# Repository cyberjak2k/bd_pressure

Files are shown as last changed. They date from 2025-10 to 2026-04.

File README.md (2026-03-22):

#  Auto PA Calibration

## Overview 

Pressure Advance (PA) is one of the most impactful tuning parameters in FDM printing, yet calibrating it correctly is time-consuming, requires print-specific expertise, and must be repeated whenever filament, speed, or temperature changes.

**bd_pressure** solves this with a dedicated strain-gauge sensor module that measures extruder pressure directly — without printing a single line. It runs an automated calibration routine by simulating extrusion pressure behaviour during acceleration and deceleration, then reports the optimal PA value to the printer firmware over USB or I2C.

The same hardware doubles as a high-precision nozzle probe for bed levelling, acting as a drop-in switch-type endstop on the Z− pin.

 
 
---
Video : https://youtu.be/xD0XgPfmwlg



## Features

| Feature | Description |
|---|---|
| **Automatic PA calibration** | No calibration prints. Extruder-only routine measures pressure response directly. |
| **Nozzle probe** | Strain-gauge contact detection for Z homing, Z tilt, bed mesh or work with eddy bed scan sensor. |
| **EMI immunity** | Sensor mounted zero-distance to PCB — minimal analog trace length eliminates noise pickup. |
| **USB & I2C** | Flexible host connectivity; works with Klipper and compatible setups. |
| **Broad compatibility** | Mounting footprint compatible with E3D and Voron toolhead ecosystems. |

---

## How It Works

### Mode 1 — Pressure Advance Calibration

Rather than printing calibration patterns and analysing them visually, bd_pressure directly measures the mechanical relationship between extruder motor acceleration and filament pressure at the nozzle.

1. The extruder motor runs a controlled acceleration/deceleration sequence.
2. The strain gauge measures the resulting force in real time.
3. The on-board MCU fits a pressure-vs-acceleration curve and derives the optimal PA value.
4. The result is sent to the printer firmware via USB or I2C.

This approach is conceptually similar to the automated calibration used in the Bambu Lab A1, but uses a **strain gauge** rather than an eddy current sensor — providing a direct force measurement.

### Mode 2 — Nozzle Probe

bd_pressure operates as a standard switch-type endstop sensor:

1. The printer issues a normal Z homing move.
2. As the nozzle contacts the bed, the strain gauge detects the resulting force change.
3. The module asserts a signal on the endstop output — compatible with any mainboard Z− pin.
4. No additional firmware plugin is required for basic probe operation.

---

 

---

---
 
## Installation & Documentation
 
Full installation guide, wiring diagrams, and Klipper configuration reference:
 
**[pandapi3d.cn/en/bdpressure/home](https://pandapi3d.cn/en/bdpressure/home)**


---
 
## Community & Support
 
| Channel | Link |
|---|---|
| Discord | [discord.gg/z6ahddnGVU](https://discord.gg/z6ahddnGVU) |
| Facebook group | [facebook.com/groups/380795976169477](https://www.facebook.com/groups/380795976169477) |
| Shop | [pandapi3d.com](https://www.pandapi3d.com/product-page/bdpressuree) |

---

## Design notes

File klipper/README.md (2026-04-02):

## klipper 

#### 1. Install software module
```
cd  ~
git clone https://github.com/markniu/bd_pressure.git
chmod 777 ~/bd_pressure/klipper/install.sh
~/bd_pressure/klipper/install.sh
```

#### 2. Configure Klipper

Add [include bd_pressure.cfg] into the printer.cfg , and modify the pins to your actual use in the section [probe] and [bdpressure bd_pa]

#### 3. OrcaSlicer:

1. Disable the Pressure advance in the Material settings.

2. Add the following G-code lines into the beginning of the Start_Gcode in the slicer, then it will do pressure advance calibration with your setting and automatically set the right PA value. 
```
G28                    ; Home all the axis
G1 Z30                 ; move to the poop position
G1 X240 Y240   
PA_CALIBRATE NOZZLE_TEMP=[first_layer_temperature] MAX_VOLUMETRIC=[filament_max_volumetric_speed] ACC_WALL=[outer_wall_acceleration]  TRAVEL_SPEED=[travel_speed]  ACC_TO_DECEL_FACTOR=[accel_to_decel_factor]
```
#### 3. Prusa Slicer:
```
G28                    ; Home all the axis
G1 Z30                 ; move to the poop position
G1 X240 Y240   
PA_CALIBRATE NOZZLE_TEMP=[first_layer_temperature] MAX_VOLUMETRIC=[filament_max_volumetric_speed] ACC_WALL=[outer_wall_acceleration]  TRAVEL_SPEED=[travel_speed]  MINIMUM_CRUISE_RATIO=0.5 #ACC_TO_DECEL_FACTOR=[accel_to_decel_factor] this klipper specifc variable was replaced in Klipper with MINIMUM_CRUISE_SPEED. and the 0.5 is the default 50% which can be adjusted to suite the printer's capabilities. 
```

#### bd_pressure.cfg considerations:
If you have both a bd_pressure and as well bd_width, each has the same by-id UUID because of this, each plugin will try and take control of the first device it can see with the UUID for the USB example 
So you would:
unplug bd_pressure usb cable, then use ls /dev/serial/by-path and take note of the entries there, then plug it back in and use the new entry that appears in place of the "ReplaceWithYourDevicePath" in the example below. 
you will only have to repeat this process if you change what port the bd_pressure is plugged into.
as well you will need to do this in bd_width.cfg as well as both devices will still show the by-id string and can still select the wrong device. 

##   usb example 
# port:usb
# serial:/dev/serial/by-id/usb-1a86_USB_Serial-if00-port0  ## uncomment this if you only have bd_pressure an no bd_width device
# serial:/dev/serial/by-path/ReplaceWithYourDevicePath  # Uncomment this if you have both bd_pressure and bd_width. You need to use ls /dev/serial/by-path , and determine which entry belongs to bd_pressure. 
#if you change the port it's plugged into, you will need to adjust this after doing so to reflect the new usb port you moved it to. 
#you also repeat this with bd_width.cfg to resolve the conflict.
# baud:38400

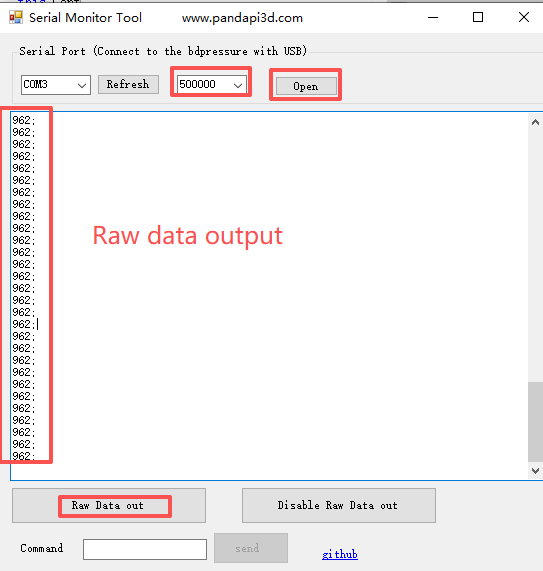
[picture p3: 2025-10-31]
tool/data.png

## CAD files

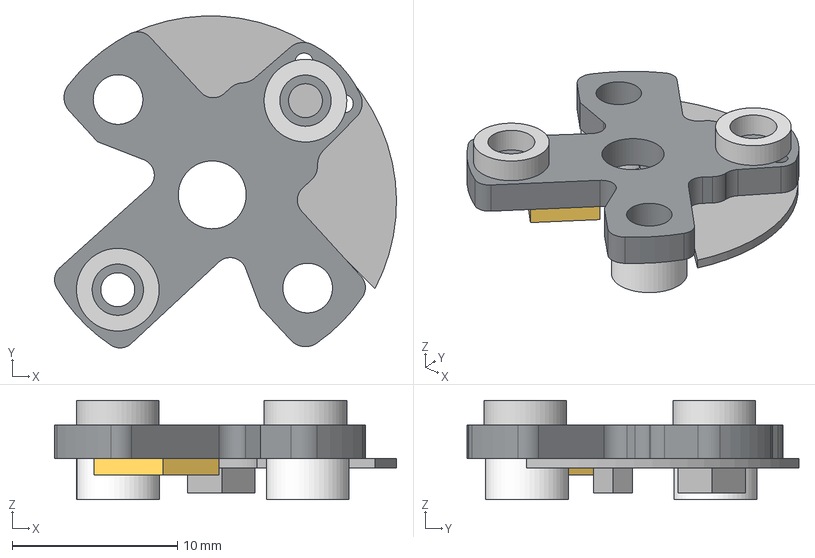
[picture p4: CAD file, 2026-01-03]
hardware/bdpressureE/bda.step
20.7 x 20.1 x 6.00 mm

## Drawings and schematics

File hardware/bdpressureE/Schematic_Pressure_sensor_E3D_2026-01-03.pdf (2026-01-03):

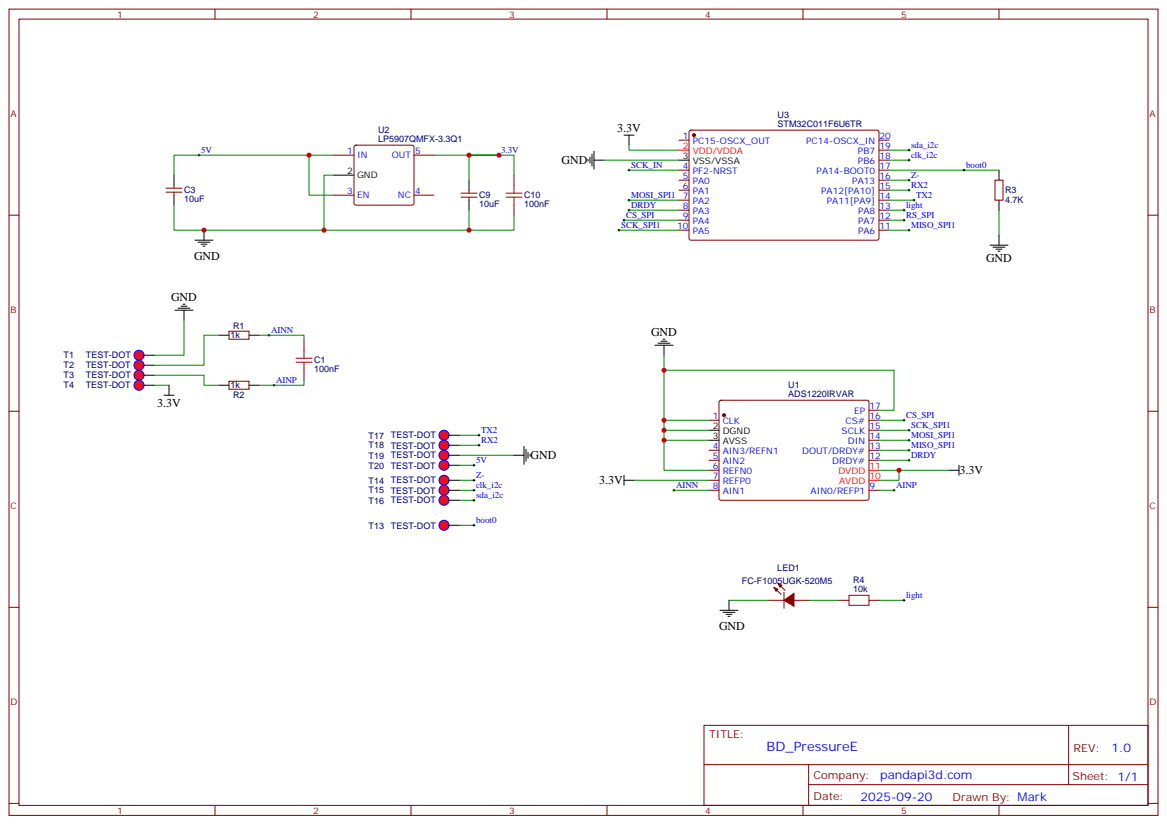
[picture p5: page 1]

ADS1220IRVAR
AVDD 10 DVDD 11 DRDY# 12 DOUT/DRDY# 13 DIN 14 SCLK 15 CS# 16 EP 17

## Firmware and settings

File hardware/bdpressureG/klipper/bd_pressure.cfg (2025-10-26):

[probe]
pin: MKS_THR:PB9
x_offset: 0
y_offset: 0
z_offset: -0.14
speed: 10
samples: 2
samples_result: median
sample_retract_dist: 3
samples_tolerance: 0.02
samples_tolerance_retries: 5

[bdpressure bd_pa]
##   usb example 
#port:usb
#serial:/dev/serial/by-path/platform-xhci-hcd.0.auto-usb-0:1.2:1.0-port0

##   i2c example
port:i2c
i2c_mcu: MKS_THR
i2c_software_scl_pin:MKS_THR:PB3
i2c_software_sda_pin:MKS_THR:PB4



[gcode_macro PA_STATE]
gcode:
    {% set status = printer["bdpressure bd_pa"].state %} 
    { action_respond_info("status:%s %d"%(status,params.T|int)) }


[gcode_macro PA_E]
gcode:   
      {% set status = printer["bdpressure bd_pa"].state %} 
      {% set i = params.I|int %} 
      #{ action_respond_info("status:%f %d"%(params.STEP|float,i)) }
      {% if status=='START' %}
        {% set pressure_ad = 0 + i*(params.STEP|float) %}
        SET_PRESSURE_ADVANCE ADVANCE={pressure_ad}
        {% set y_step =38.75 + i*3.5 %}
        G1 X78 Y{y_step} F{params.T_SPEED|int}
        G1 F{params.L_SPEED|int}
        G1 X98 Y{y_step} E.92643
        G1 F{params.H_SPEED|int}
        G1 X138 Y{y_step} E1.85285
        G1 F{params.L_SPEED|int}
        G1 X158 Y{y_step} E.92643
        SET_BDPRESSURE NAME=bd_pa COMMAND=READ VALUE={pressure_ad}
      {% endif %}
    

[gcode_macro PA_CALIBRATE]
gcode:
    # PA_CALIBRATE NOZZLE_TEMP=[first_layer_temperature] MAX_VOLUMETRIC=[filament_max_volumetric_speed] ACC_WALL=[outer_wall_acceleration]
    # TRAVEL_SPEED=[travel_speed]  ACC_TO_DECEL_FACTOR=[accel_to_decel_factor]

    ### temperature=210,ACCEL_TO_DECEL=10000,ACCEL=8000,SQUARE_CORNER_VELOCITY=5
    {% set NOZZLE_TEMP = 210 %}
    {% if params.NOZZLE_TEMP %}
	      { action_respond_info("nozzle TEMPERATURE %s "%params.NOZZLE_TEMP) }
	      {% set NOZZLE_TEMP = params.NOZZLE_TEMP|default(210)|float %}
	  {% endif %}
    {% set ACC_WALL = 4000 %}
    {% if params.ACC_WALL %}
	      { action_respond_info("ACC_out_WALL %s "%params.ACC_WALL) }
	      {% set ACC_WALL = params.ACCEL_TO_DECEL|default(4000)|float %}
	  {% endif %}

    {% set SQUARE_CORNER_SPEED = 9 %}
    {% if params.SQUARE_CORNER_VELOCITY %}
	      { action_respond_info("SQUARE_CORNER_VELOCITY %s "%params.SQUARE_CORNER_VELOCITY) }
	      {% set SQUARE_CORNER_SPEED = params.SQUARE_CORNER_VELOCITY|default(9)|float %}
	  {% endif %}
    ### travel_speed=400, max_volumetric_speed = [filament_max_volumetric_speed]
    ##  low_speed = (1020/20)*max_volumetric_speed
    ##  high_speed = (10740/20)*max_volumetric_speed
    {% set ACC_TO_DECEL_FAC = 0.5 %}
    {% set MIN_CRUISE = 0.5 %}
    {% if params.ACC_TO_DECEL_FACTOR %}
	      { action_respond_info("accel_to_decel_factor %s "%params.ACC_TO_DECEL_FACTOR) }
	      {% set ACC_TO_DECEL_FAC =  params.ACC_TO_DECEL_FACTOR.replace("%", "").strip() | float / 100    %}
	      {% set MIN_CRUISE = 1-ACC_TO_DECEL_FAC|float %}
          { action_respond_info("ACC_TO_DECEL_FACTOR %s "%ACC_TO_DECEL_FAC) }
          { action_respond_info("MIN_CRUISE %s "%MIN_CRUISE) }
	  {% endif %}
    {% set ACC_TO_DEC = ACC_TO_DECEL_FAC*ACC_WALL %}
    
    {% set TRAVEL_SPEED = 400 %}
    {% if params.TRAVEL_SPEED %}
	      {% set TRAVEL_SPEED = params.TRAVEL_SPEED|default(400)|float * 60 %}
          { action_respond_info("travel_speed %s/60 "%TRAVEL_SPEED) }
	  {% endif %}
    {% set MAX_VOLUMETRIC = 20 %}
    {% if params.MAX_VOLUMETRIC %}
	      { action_respond_info("filament_max_volumetric_speed %s "%params.MAX_VOLUMETRIC) }
	      {% set MAX_VOLUMETRIC = params.MAX_VOLUMETRIC|default(20)|float %}
	  {% endif %}
    {% set low_speed = 51*MAX_VOLUMETRIC %}
    { action_respond_info("low_speed %f "%low_speed) }
    {% set high_speed = 537*MAX_VOLUMETRIC %}
    { action_respond_info("high_speed %f "%high_speed) }
    
    #  volum=[filament_max_volumetric_speed]
    #  travel=[travel_speed] [accel_to_decel_factor] acc=[outer_wall_acceleration] temper=[first_layer_temperature]
    #SET_KINEMATIC_POSITION Z={z_current}
    {% set z_current=printer.toolhead.position.z %}
    G90
    G21
    M83 
    M109 S{NOZZLE_TEMP}
    G1 E4
    SET_PRESSURE_ADVANCE ADVANCE=0.04; Override pressure advance value
    SET_VELOCITY_LIMIT ACCEL={ACC_WALL} ACCEL_TO_DECEL={ACC_TO_DEC}
    SET_VELOCITY_LIMIT ACCEL={ACC_WALL} MINIMUM_CRUISE_RATIO={MIN_CRUISE}
    SET_VELOCITY_LIMIT SQUARE_CORNER_VELOCITY={SQUARE_CORNER_SPEED}
    
    
    SET_STEPPER_ENABLE STEPPER=stepper_x ENABLE=1
    SET_STEPPER_ENABLE STEPPER=stepper_y ENABLE=1
    SET_BDPRESSURE NAME=bd_pa COMMAND=START
    M400
    G4 P1000
    {% set y_step = 38.75 %}
    {% set pressure_ad = 0 %}
    {% set pressure_step = 0.002 %}
    
    G1 F{high_speed}
    G1 X78 Y{y_step} E9.92204
    M400
    G4 P4000
    G1 F{low_speed}
    G1 X98 Y{y_step} E.92643
    G1 X138 Y{y_step} E1.85285
    G1 X158 Y{y_step} E.92643
    G1 X78 Y{y_step} F{TRAVEL_SPEED}
    ######
    M400
    {% for i in range(50) %}
       PA_E STEP={pressure_step} T_SPEED={TRAVEL_SPEED} H_SPEED={high_speed} L_SPEED={low_speed} I={i}
    {% endfor %}
    M400 
    SET_BDPRESSURE NAME=bd_pa COMMAND=STOP
    G4 P1000
    SET_KINEMATIC_POSITION X=0 Y=0
    G28 X
    G28 Y
    SET_KINEMATIC_POSITION Z={z_current}
    #G28 Z

    
    

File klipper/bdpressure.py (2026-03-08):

import logging
import math
import statistics
import serial
import os


from . import bus
from . import filament_switch_sensor


BDP_CHIP_ADDR = 4
BDP_I2C_SPEED = 100000
BDP_REGS = {
     '_version' : 0x0,
     '_measure_data' : 15,
      'pa_probe_mode' : 48, ## 7= CLOCK_OSR_16384  2=CLOCK_OSR_512
     'raw_data_out' : 49,
     'probe_thr' : 50,
     'rang' : 51,
     'reset_probe' : 52,
     'invert_data' : 53

}

PIN_MIN_TIME = 0.100
RESEND_HOST_TIME = 0.300 + PIN_MIN_TIME
MAX_SCHEDULE_TIME = 5.0


class BD_Pressure_Advance:
    def __init__(self, config):
        self.printer = config.get_printer()
        self.reactor = self.printer.get_reactor()
        self.port = config.get("port")
        self.old_res=''
        # if config.get("resistance1", None) is None:
        self.thrhold = config.getint('thrhold', 4, minval=1) 
        if "i2c" in self.port:  
            self.i2c = bus.MCU_I2C_from_config(config, BDP_CHIP_ADDR, BDP_I2C_SPEED)
        elif "usb" in self.port:
            self.usb_port = config.get("serial")
            self._baud = config.getint('baud', 38400, minval=2400) 
            #THRHOLD
           # baudrate = self.usb_port = config.get("") #38400
            self.usb = serial.Serial(self.usb_port, self._baud,timeout=0.5)
            self.usb.reset_input_buffer()
            self.usb.reset_output_buffer()
        self.PA_data = []    
        self.bd_name = config.get_name().split()[1]     
        self.gcode = self.printer.lookup_object('gcode')
        self._invert_stepper_x, self.mcu_enable_pin_x = self.enable_pin_init(config,"stepper_x")
        self._invert_stepper_x1, self.mcu_enable_pin_x1 = self.enable_pin_init(config,"stepper_x1")
        self._invert_stepper_y, self.mcu_enable_pin_y = self.enable_pin_init(config,"stepper_y")
        self._invert_stepper_y1, self.mcu_enable_pin_y1 = self.enable_pin_init(config,"stepper_y1")
        self.last_state = 0
        self.gcode.register_mux_command("SET_BDPRESSURE", "NAME", self.bd_name,
                                   self.cmd_SET_BDPRESSURE,
                                   desc=self.cmd_SET_BDPRESSURE_help)   
        self.printer.register_event_handler('klippy:ready',
                                                self._handle_ready)
        self.printer.register_event_handler("homing:homing_move_begin",
                                            self.handle_homing_move_begin)                                        

    def set_probe_mode(self):
        response = ""
        if "usb" == self.port:
            self.usb.write('e;'.encode())
            self.usb.write((str(self.thrhold)+';').encode())
           # response += self.usb.readline().decode('utf-8').strip()
        elif "i2c" == self.port: 
           # response += self.read_register('_version', 15).decode('utf-8')
            #self.write_register('endstop_thr',6)
            self.write_register('pa_probe_mode',2)
            self.write_register('probe_thr',self.thrhold)


    def _handle_ready(self):
        #self.set_probe_mode()
        self.toolhead = self.printer.lookup_object('toolhead')
        
         
    def handle_homing_move_begin(self, hmove):
        self.set_probe_mode()
       # if self.mcu_probe in hmove.get_mcu_endstops():
        #    self.mcu_probe.probe_prepare(hmove)        
        
    cmd_SET_BDPRESSURE_help = "cmd for BD_PRESSURE sensor,SET_BDPRESSURE NAME=xxx COMMAND=START/STOP/RESET_PROBE/READ VALUE=X"
    def cmd_SET_BDPRESSURE(self, gcmd):
        # Read requested value
        cmd = gcmd.get('COMMAND')
       # self.gcode.respond_info("Send %s to bdpressure:%s"%(cmd,self.bd_name))
        if 'START' in cmd:
            self.cmd_start(gcmd)
        elif 'STOP' in cmd:  
            self.cmd_stop(gcmd)
        elif 'RESET_PROBE' in cmd:  
            self.cmd_reset_probe(gcmd) 
        elif 'READ' in cmd:  
            self.cmd_read(gcmd)  
        
            
            
    def _resend_current_val(self, eventtime):
        if self.last_value == self.shutdown_value:
            self.reactor.unregister_timer(self.resend_timer)
            self.resend_timer = None
            return self.reactor.NEVER

        systime = self.reactor.monotonic()
        print_time = self.mcu_enable_pin_x.get_mcu().estimated_print_time(systime)
       # print_time = self.mcu_enable_pin_y.get_mcu().estimated_print_time(systime)
        time_diff = (self.last_print_time + self.resend_interval) - print_time
        if time_diff > 0.:
            # Reschedule for resend time
            return systime + time_diff
        self._set_pin(print_time + PIN_MIN_TIME, self.last_value, True)
        return systime + self.resend_interval

    def enable_pin_init(self, config, stepper_name):

        stconfig = config.getsection(stepper_name) 
        if stconfig is None:
            return None, None
        enable_pin_s = stconfig.get('enable_pin', None) 
        if enable_pin_s is None:
            return None, None
        logging.info(" init %s"%(stepper_name))       
        self.printer = config.get_printer()
        ppins = self.printer.lookup_object('pins')
        # Determine pin type

        pin_params = ppins.lookup_pin(enable_pin_s, can_invert=True, can_pullup=True,share_type='stepper_enable')
        mcu_pin_s = pin_params['chip'].setup_pin('digital_out', pin_params)
        _invert_stepper = pin_params['invert']
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

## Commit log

2025-10-26 fix a bug switch between probe mode and pa mode
    [bdpressure.py]
2026-01-03 update files for bdpressureE
    [bd_pressure.cfg, bda.step]
2026-02-26 Refactor PA_RESET G-code commands in bd_pressure.cfg
    Removed commented G-code commands and simplified PA_RESET macro.
    [bd_pressure.cfg]
2026-03-03 fix a bug for calculate the best PA value
    [bdpressure.py]
2026-03-08 fix a i2c bug for the latest klipper
    [bdpressure.py]
2026-03-10 fix a bug 'stepper too far in past'
    [bd_pressure.cfg]
2026-04-02 Update README with bd_pressure and bd_width instructions
    Added considerations for bd_pressure and bd_width configuration to avoid USB device conflicts.

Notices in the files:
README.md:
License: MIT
